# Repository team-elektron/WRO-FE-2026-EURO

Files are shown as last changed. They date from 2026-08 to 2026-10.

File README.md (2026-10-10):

# Elektron Team - WRO Future Engineers 2026 - European Open

## Introduction

We are Team Elektron from the High School of Electrical Engineering in Sarajevo, Bosnia & Herzegovina.
This is the public repo for our team and the work we have done on our robot for the Open Championship in Zagreb.

### Sponsors

This year we have the privilege of working together with our sponsors.

<table>
  <tr>
    <td width="25%" valign="center">
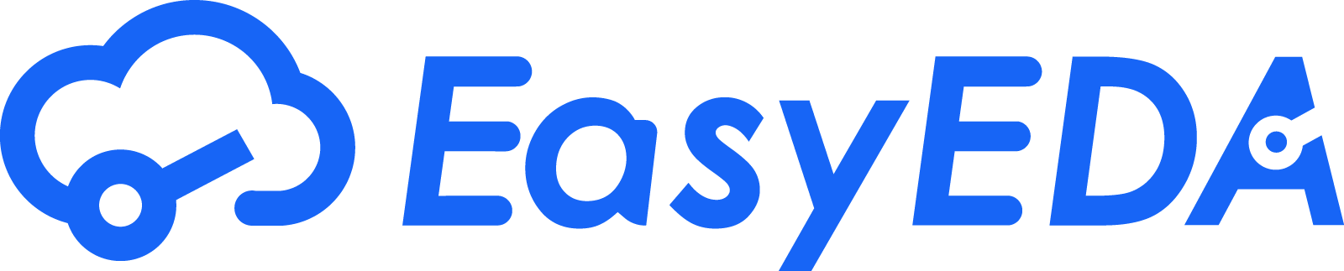
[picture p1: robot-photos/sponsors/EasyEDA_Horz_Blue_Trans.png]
EasyEDA
      
    </td>
    <td width="25%" valign="center">
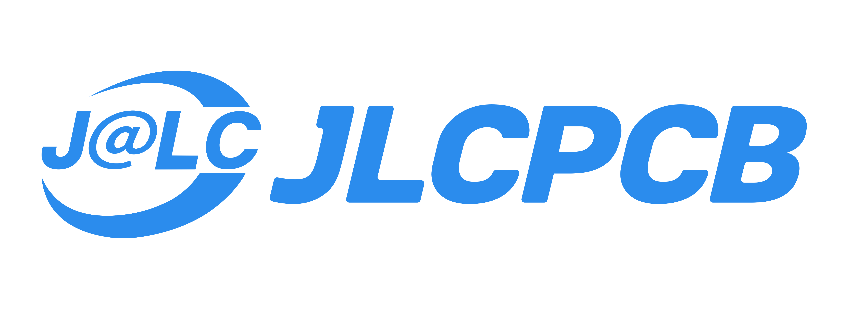
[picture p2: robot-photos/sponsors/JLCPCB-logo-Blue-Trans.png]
JLCPCB
      
    </td>
    <td width="25%" valign="center">
      <center><summary><h1>Birisal D.O.O.</h1></summary></center>
    </td>
  </tr>
</table>

### Robot Gallery

<table>
  <tr>
    <td width="25%" valign="center">
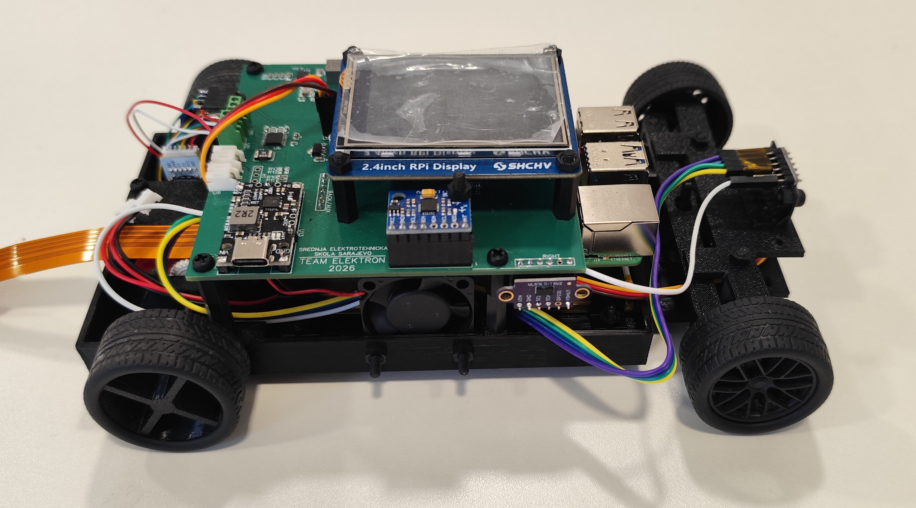
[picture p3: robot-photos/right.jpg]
      
    </td>
    <td width="25%" valign="center">
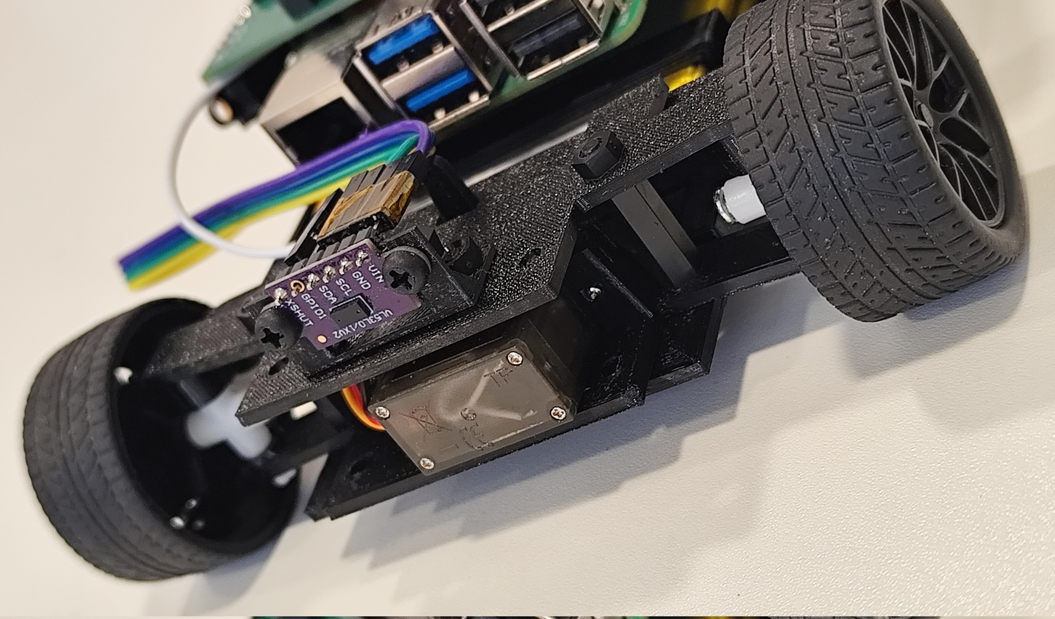
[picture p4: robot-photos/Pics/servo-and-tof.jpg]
      
    </td>
  </tr>
</table>

### Team Photo

<table>
  <tr>
    <td width="25%" valign="center">
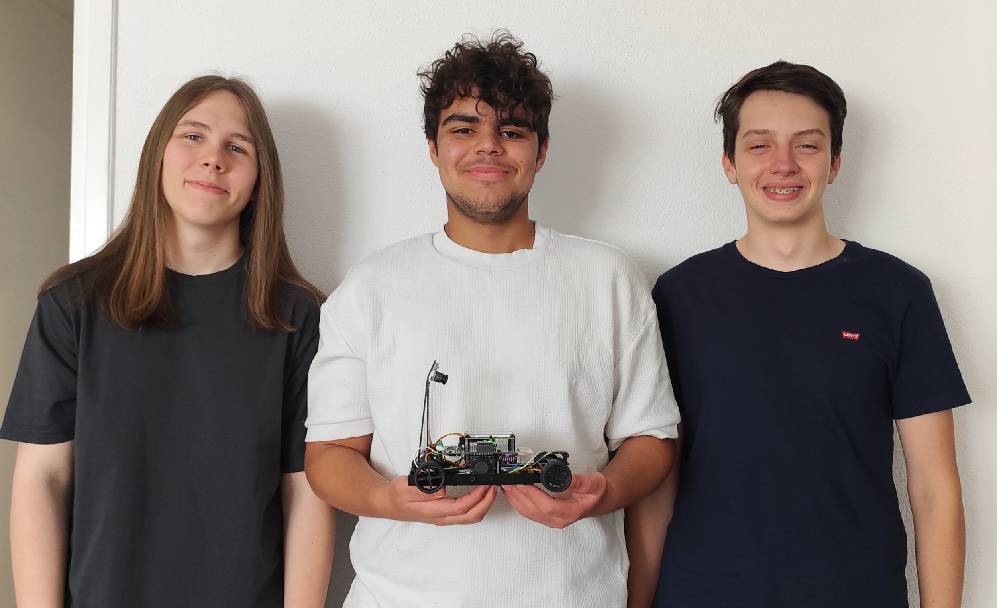
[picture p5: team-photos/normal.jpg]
      
    </td>
  </tr>
</table>

## Folder Content
* `team-photos` contains 2 photos of the team (an official one and one funny photo with all team members)
* `robot-photos` contains 6 photos of the vehicle (from every side, from top and bottom)
* `videos` contains the video.md file with the link to a video where driving demonstration exists
* `schematics` contains schematic diagrams of the driving base.
* `code` contains code of control software for all components which were programmed to participate in the competition.
* `3d-models` is for the files for models used by 3D printers to produce the vehicle elements.

## Navigation

- <a href="#introduction">Introduction</a>
- <a href="#sponsors">Sponsors</a>
- <a href="#team-photo">Team Photo</a>
- <a href="#robot-gallery">Robot Gallery</a>
- <a href="#changes-summary-from-the-national-competition">Changes summary from National Competition/a>
- <a href="#technical--mechanical-specifications">Technical & Mechanical Specifications</a>
  - <a href="#mechanics--drive">Mechanics & Drive</a>
  - <a href="#electronics">Electronics</a>
  - <a href="#size">Size</a>
- <a href="#how-does-it-work">How does it work?</a>
  - <a href="#driving-system">Driving System</a>
  - <a href="#steering-system">Steering System</a>
  - <a href="#power-and-power-delivery">Power & Power delivery system</a>
  - <a href="#the-brain">The brain (SBC, MCU)</a>
  - <a href="#sensors">Sensors</a>
- <a href="#bill-of-materials">Bill of Materials</a>
- <a href="#the-assembly-process-and-future-improvements">The assembly process and future improvements</a>
  - <a href="#pcb-assembly">PCB Assembly</a>
  - <a href="#3d-print--assembly">3d Print & Assembly</a>
- <a href="#code-explanation">Code Explanation</a>
  - <a href="#raspberry-pi-pico-2---pi-5-communications-bridge">Raspberry Pi Pico 2 <-> Pi 5 Communications bridge</a>
  - <a href="#open-challenge">Open Challenge</a>
  - <a href="#obstacle-challenge">Obstacle Challenge</a>

## Changes summary from the National competition
Our robot base has had major improvements done to it after the National championship in Zenica, Bosnia & Hercegovina.

Some of the biggest changes include:
- New motor/shaft gear ratio
- New robot control PCB
- New chassis design

## Technical & Mechanical Specifications

### Mechanics & Drive
- Fully custom built and 3d printed robot base
- High torque, high speed driving system
- Servo steering system

### Electronics
- 5Ah 2S battery pack (Li-Po)
- Time-of-Flight distance sensors
- Raspberry Pi 5 8GB SBC
- Raspberry Pi Pico 2 Zero MCU
- Full-axis IMU sensor
- Addressable LED indicators
- 2.4in TFT Touch Control LCD
- Raspberry Pi Camera Module 2 160 degree FOV

### Size
- 205x135x65mm (LxWxH) without camera mount, 205x135x~150mm (LxWxH) with camera mount
- ~490g total weight

<table>
  <tr>
    <td width="25%" valign="center">
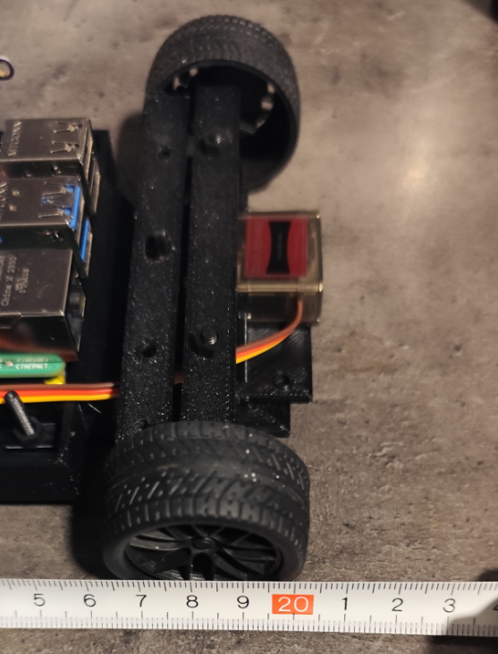
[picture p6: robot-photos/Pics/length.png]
      
    </td>
    <td width="25%" valign="center">
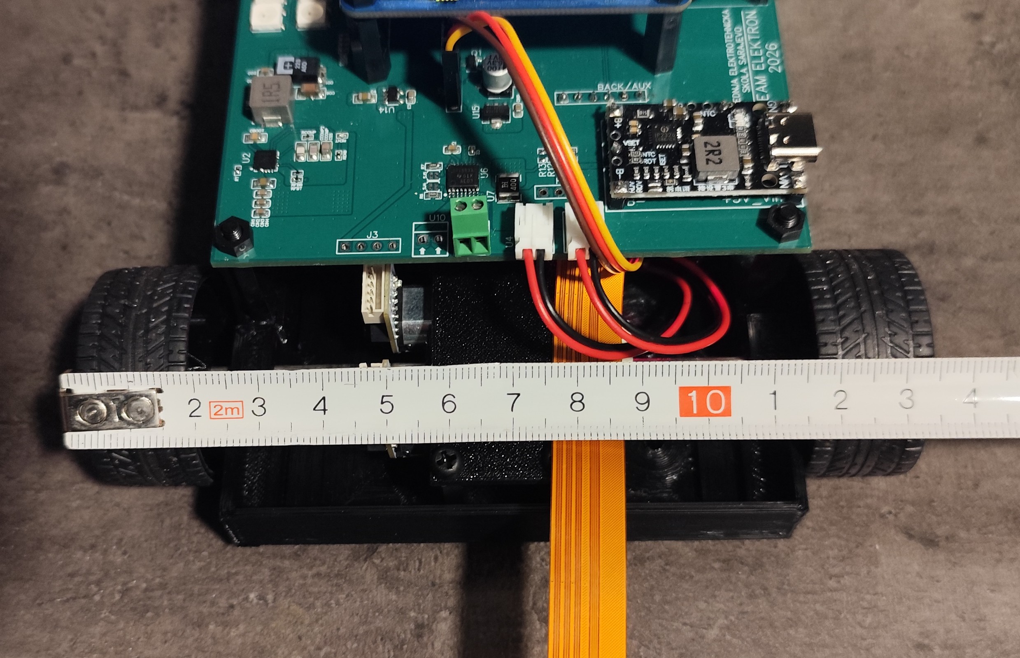
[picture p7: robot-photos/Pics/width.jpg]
      
    </td>
    <td width="25%" valign="center">
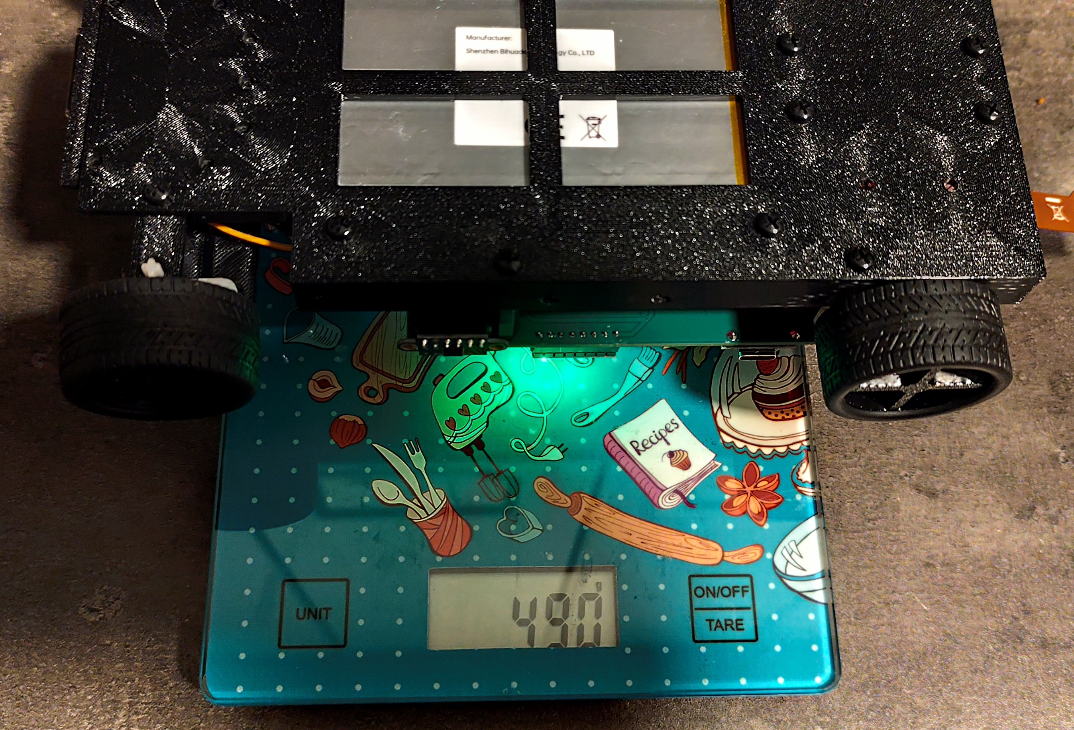
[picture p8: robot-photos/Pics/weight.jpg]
      
    </td>
  </tr>
</table>

## How does it work?

### Driving system
The main driving motors are 2 N30 motors in a 1:150 configuration, then the power is transferred to the wheels with a 1.67:1 gear ratio, the motors feature hall effect sensors. 

<table>
  <tr>
    <td width="25%" valign="center">
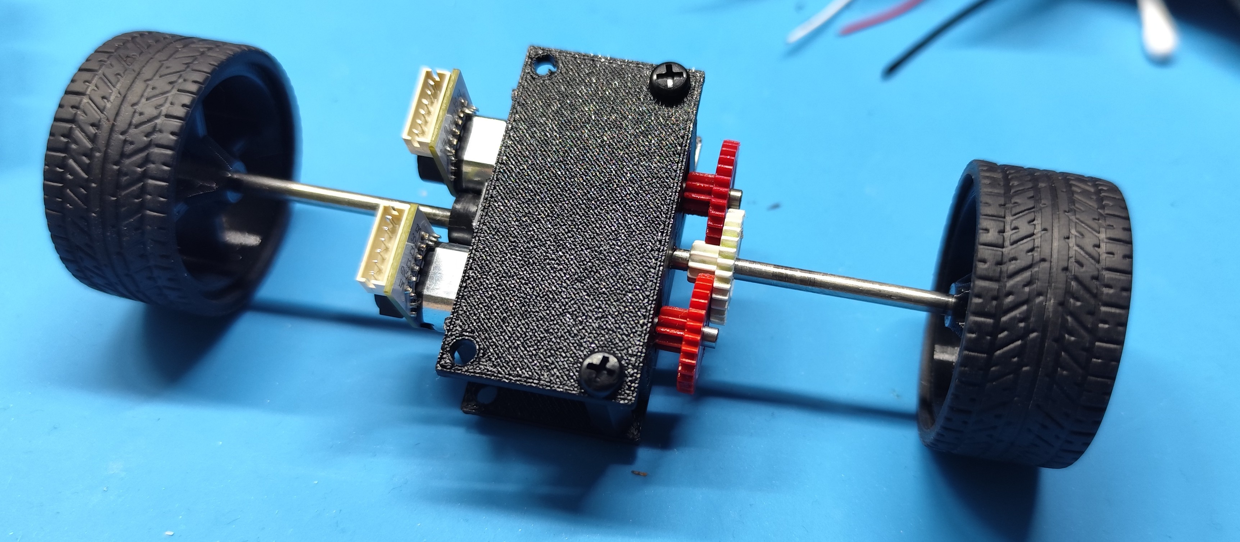
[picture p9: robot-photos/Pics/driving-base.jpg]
      
    </td>
    <td width="25%" valign="center">
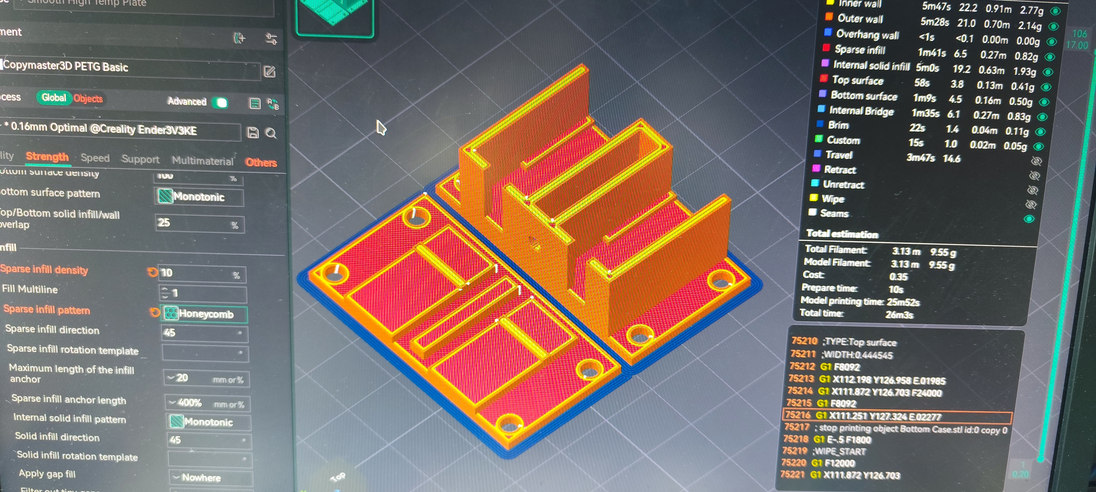
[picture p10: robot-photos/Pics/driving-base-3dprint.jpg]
      
    </td>
  </tr>
</table>

We have tested a couple different configurations (mainly 1:3, 1:1 and 1.67:1) out of which, 1.67:1 turned out to work the best for our needs. For extra torque, we decided to include 2 motors instead of one. They are connected to the DRV8833 H-Bridge IC on separate channels **BUT** the motors are connected onto one shared shaft together. The separte channels are exclusively to distribute load evenly on the IC.

<table>
  <tr>
    <th>Gear ratio (motor-shaft)</th>
    <th>Result</th>
    <th>Reasoning</th>
  </tr>
  <tr>
    <td>3:1</td>
    <td>Good speed, low torque/td>
    <td>With this combination we had very good speed, however our low end torque was very low which means parking the robot in Obstacle Challenge mode was almost impossible.</td>
  </tr>
  <tr>
    <td>1:1</td>
    <td>Slow, very torquey</td>
    <td>This gear ratio combination has really good low speed torque but it is painfully slow at full motor speed.</td>
  </tr>
  <tr>
    <td>1.67:1</td>
    <td>Decent speed, good torque</td>
    <td>This ratio has decent speed and good torque. It is OK for obstacle challenge parking.</td>
  </tr>
</table>

We are using a 110mm long and 3mm in diameter steel shaft and plastic gears.

Wheels are 3D printed, each wheel being 30mm in diameter without the outer rubber bits.

<table>
  <tr>
    <td width="25%" valign="center">
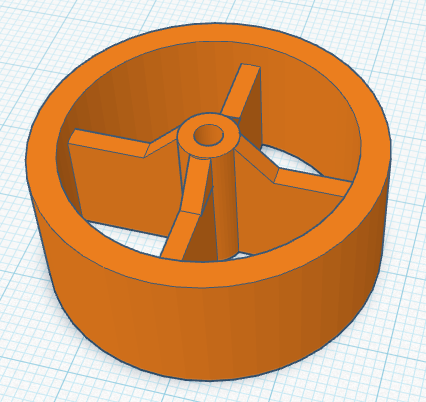
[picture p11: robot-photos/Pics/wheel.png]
      
    </td>
  </tr>
</table>

These specific motors have 2 hall effect sensors each, one for speed and one for direction, however we are only using one set from one motor, the other one stays disconnected and should only be used in case that something goes wrong with the other motor.

Speed control is done via a PID algorithm handled by the Pi Pico 2.

The motors are controlled by a DRV8833 IC which is current-limited to 1A per channel.

<table>
  <tr>
    <td width="25%" valign="center">
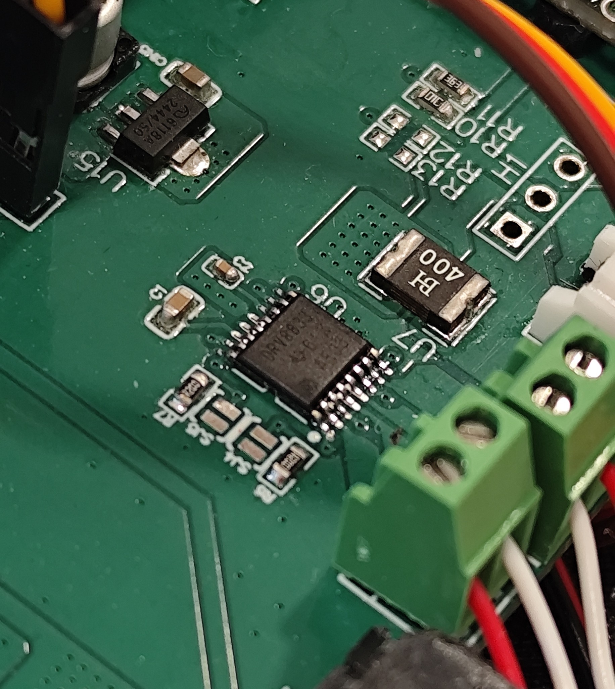
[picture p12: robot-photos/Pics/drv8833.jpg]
      
    </td>
    <td width="25%" valign="center">
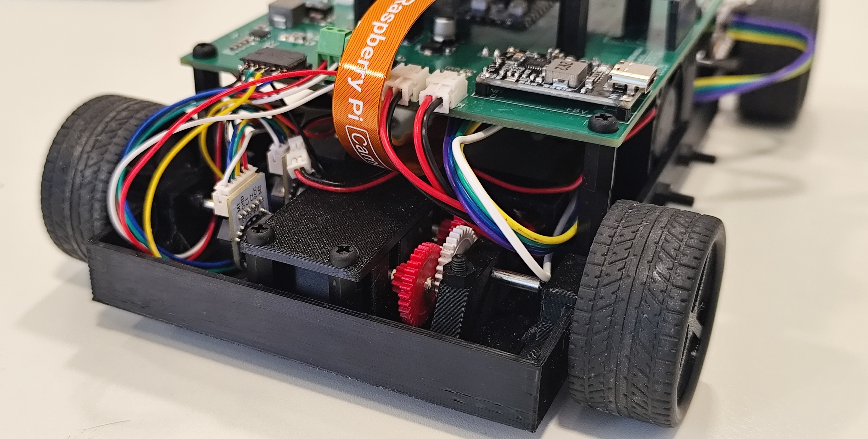
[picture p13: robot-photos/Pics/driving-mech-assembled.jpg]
      
    </td>
  </tr>
</table>

### Steering system
The steering system is controlled by one main MG90S servo from Waveshare.

Last year, we had issues with our steering system on the Open Championship in Ljubljana which was caused by a fake "metal" servo. Hence why we opted for higher quality full metal gear servos, and the MG90S was a great option as we didn't really need more power than that.

Steering power is transferred to the wheels via a steering shaft. Front wheels have bearings in them to remove drift caused by play in the old mechanism it is also used to decrease rolling resistance.
With this configuration, we are able to achieve a steering angle of 50 degrees to each side which fits our needs nicely.

<table>
  <tr>
    <td width="25%" valign="center">
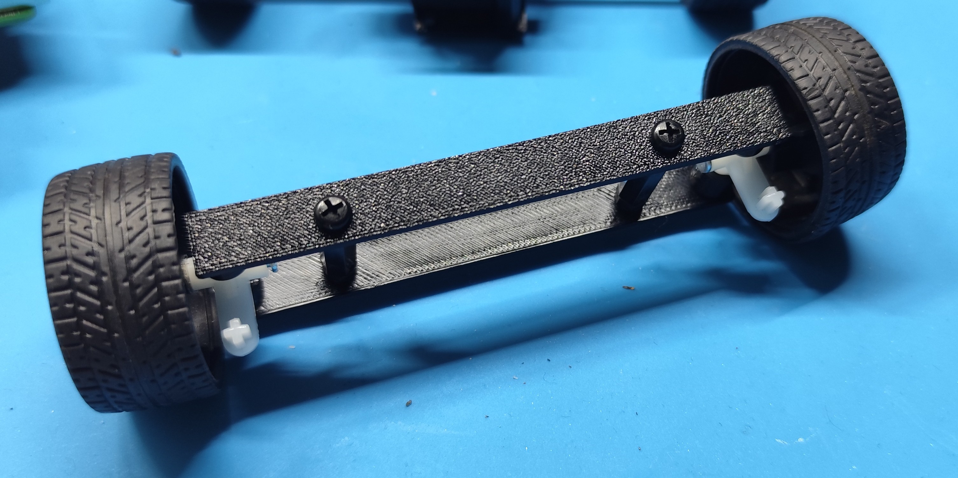
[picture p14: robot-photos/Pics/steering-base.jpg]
      
    </td>
    <td width="25%" valign="center">
      
    </td>
  </tr>
</table>

### Power and power delivery
We had originally thought about using a 3S battery system like we did last year, however, we switched to a 2S system now to save on space and weight. With some clever engineering tricks and overcomplication the power delivery side, that was super easy to do.

<p float="left">
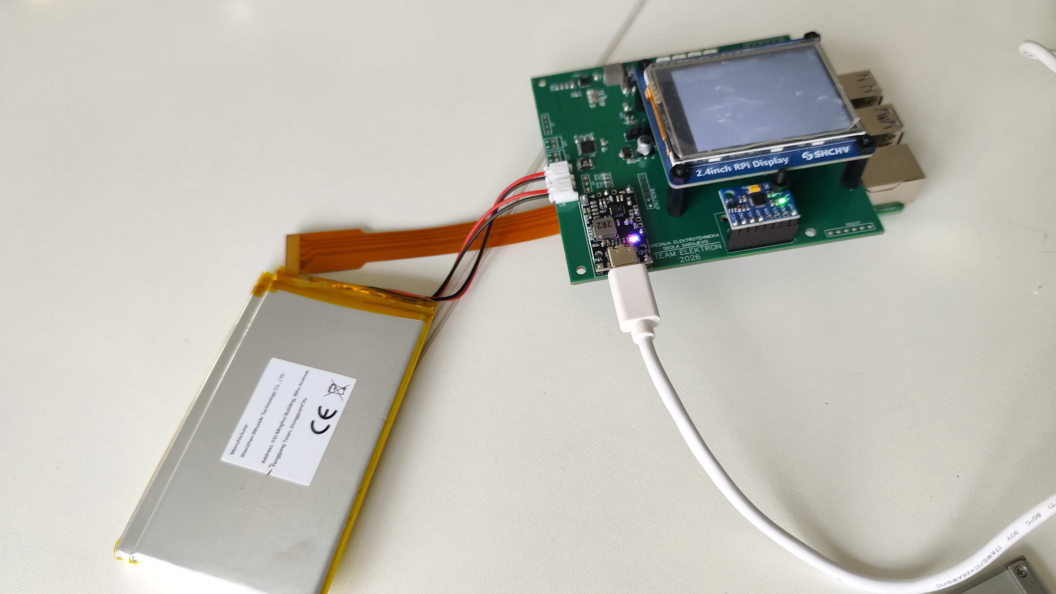
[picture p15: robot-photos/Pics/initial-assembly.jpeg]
  
  &nbsp;
</p>

The main power source are 2 5360105 Li-Po 3.7v 5Ah cells connected in series, they each have their own integrated BMS for safety.
We have decided to continue to charge our cells with a USB-C charger, but this year we have switched to a much more efficient IP2326 module for charging (and also because our previous battery had a dedicated BMS as it was built from bare 18650 cells and had balancing included which the 2 separate battery cells don't).

The actual power delivery part is split up into a couple different stages, one buck regulator for the Pi 5 exclusively and 2 smaller LDO regulators for the Pi Pico 2, sensors and another for the MG90S servo.

The main power regulator IC is a TPS54623RHLR. It's a pretty recent chip with not so much documentation available from other hobbyists but due to its very attractive price and great performance claims, we had to give it a shot. After designing a circuit that works for our needs in Ti's WEBENCH design utility (which are basically 5V output and at least 5A output max), we had ourselves a very nice and reliable regulator config. 

Robots are noisy machines, both literally in an audible sense, and power wise. Last year we had major issues with premade modules for power regulations which just couldn't handle our Pi, so this year, we decided to go overkill on ensuring our robot has clean power everywhere at all times. Our decoupling circuit includes:
  -  One 220uF 10V 10TPE220ML Panasonic Polymer Tantalum capacitor for bulk power storage.
  -  Two 10uF 6.3V X6S CL10X106MQ8NNNC Ceramic MLCC Samsung capacitors for mid frequency decoupling
  -  Four 100nF 6.3V X7R CGA0402X7R104K6R3GT Ceramic MLCC HRE capacitors for high frequency decoupling which were placed right next to the GPIO power pins of the Pi 5

<p float="left">
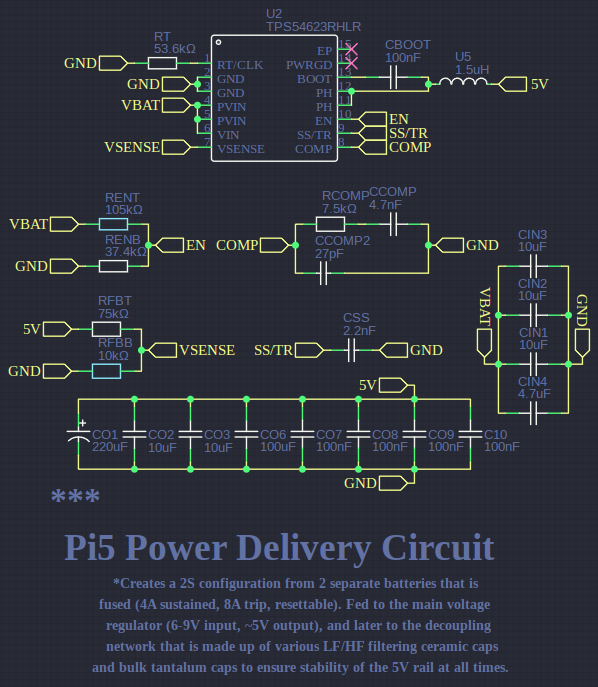
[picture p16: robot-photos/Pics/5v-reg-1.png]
  
  &nbsp;
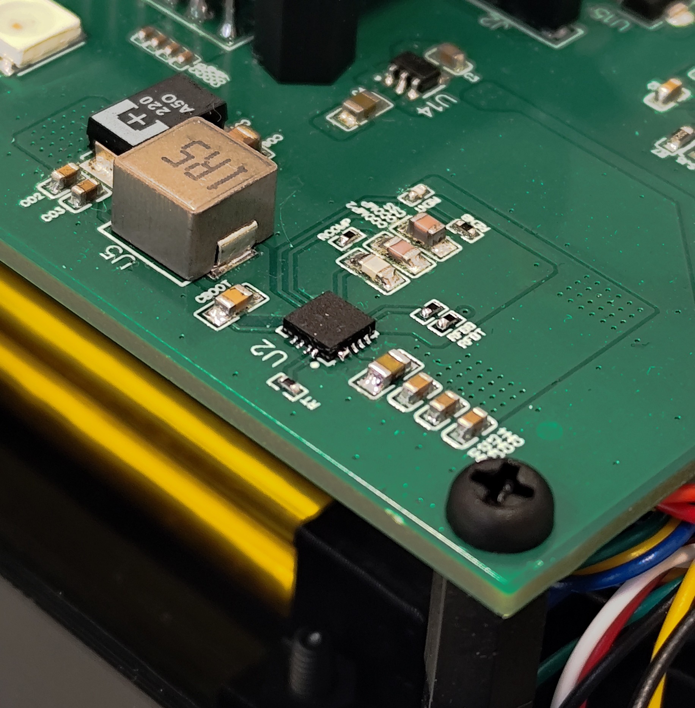
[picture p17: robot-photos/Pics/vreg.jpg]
  
</p>

For the other two power regulators, we decided to go with the following combination:
  - AP2112K-3.3TRG1 3.3V 1A LDO regulator for the Pico 2 and 3.3V sensors (ToF and IMU)
  - ME6118A50PG 5V 1A LDO regulator for our MG90S servo

<p float="left">
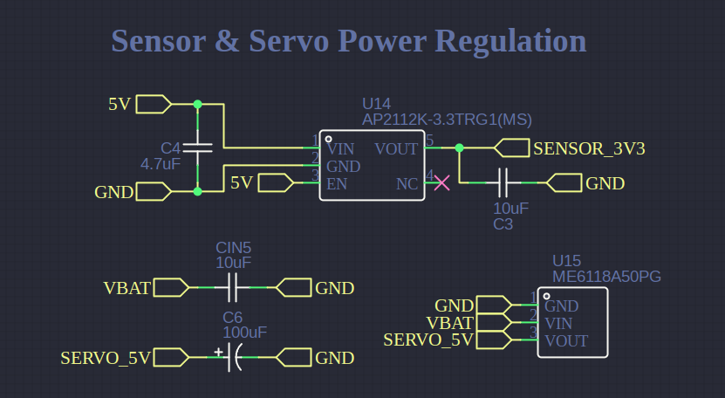
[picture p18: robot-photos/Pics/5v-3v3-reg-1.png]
  
  &nbsp;
</p>

### The Brain
Our robot runs on a Raspberry Pi 5 (8GB). We chose this SBC because we had it available and because the only other option we had was a Pi 4 with 2GB of ram. The choice is obvious :D
The Pi 5 communicates with the Pi Pico 2 Zero through UART on pins GP14/15 (and pins GP0/1 on the Pico 2). 

Workloads are distributed between both the SBC and the MCU like this:
<p float="left">
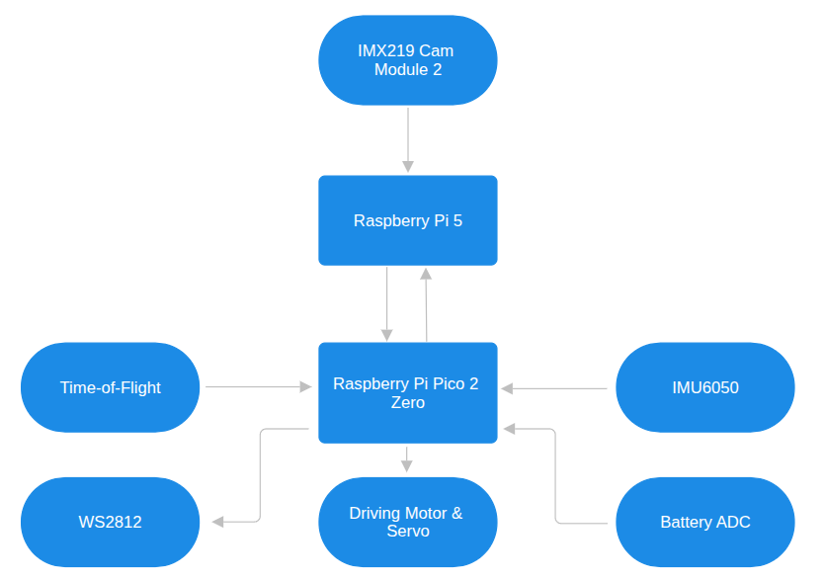
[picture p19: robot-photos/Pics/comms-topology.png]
  
  &nbsp;
</p>

Pi 5 Handles camera input and OpenCV image processing and then sends movement data to the Pi Pico 2 Zero. 

We use a simple UART protocol to communicate between the SBC and MCU:
- Every packet
  
  `[0xAA] [TYPE] [LEN] [PAYLOAD...] [CRC8]`
  - `0xAA` Start byte, always
  - `TYPE` What kind of message
  - `LEN` Payload length in bytes
  - `CRC8` Checksum of everything except start byte

- Pi 5 -> Pico 2 Zero (commands): `TYPE = 0x01`
  
  `[0xAA] [0x01] [04] [dir] [speed] [servo] [led_mode] [CRC8]`
  - `dir` 0 = stop, 1 = fwd, 2 = bwd
  - `speed` 0 - 255
  - `servo` 0 - 180
  - `led_mode` 0 = idle, 1 = driving, 2 = obstacle, 3 = low battery

- Pico 2 Zero -> Pi 5 (telemetry): `TYPE = 0x02`
  
  `[0xAA] [0x02] [14] [tof0_H] [tof0_L] [tof1_H] [tof1_L] [tof2_H] [tof2_L] [tof3_H] [tof3_L] [batt_H] [batt_L] [yaw_H] [yaw_L] [enc_H] [enc_L] [CRC8]`
  - ToF values in mm, split into HI/LO bytes
  - Battery in mV
  - Yaw in tenths of a degree (so 1234 = 123.4 degrees)
  - Encoder ticks as int16

The robot is controlled through the 2.4in TFT Touchscren LCD display. It also shows all of the telemetry data collected from the Pi Pico 2 Zero and allows for manual control when debugging. The competition-ready interface will just feature a simple option to select between running the obstacle or open challenge code and one start button. 

### Sensors
After running into a lot of trouble with ultrasonic distance sensors (hc-sr04) last year, we now use Time-of-Flight distance sensors. The most readily available sensor of this kind on the market is the VL53Lx series of sensors.

We use 3 ToF sensors on the robot with the option of adding a 4th sensor (rear side sensor) if needed. The data is polled in single shot mode on each sensor for higher speed and precision.

<p float="left">
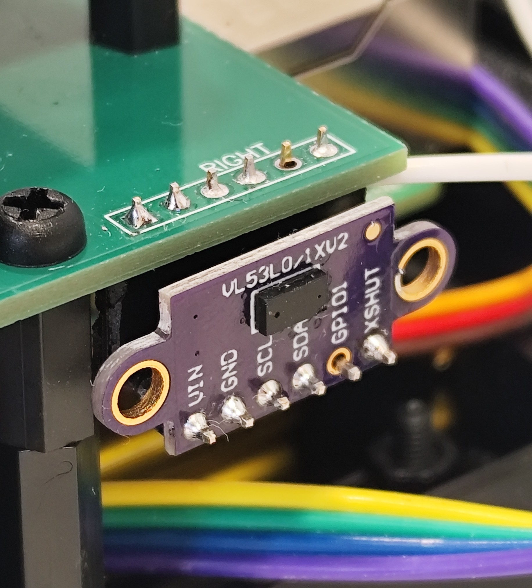
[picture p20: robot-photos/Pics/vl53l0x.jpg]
  
  &nbsp;
</p>

For getting the turn angle we use the MPU6050 IMU sensor. It's not the most accurate sensor and has a little bit of drift when idle but that's nothing resetting the sensor yaw angle before every turn cant fix. 

<p float="left">
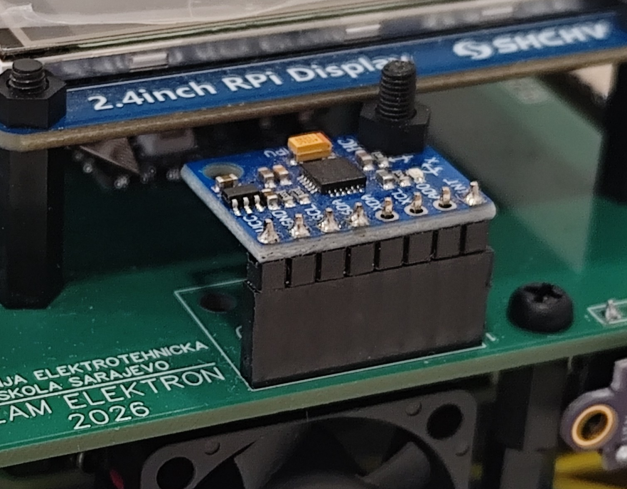
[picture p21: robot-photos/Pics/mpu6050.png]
  
  &nbsp;
</p>

## Bill Of Materials
- <a href="https://www.waveshare.com/rp2350-zero.htm">Raspberry Pi Pico 2 Zero (WaveShare)</a>
- <a href="https://sync.ba/product/raspberry-pi-5/">Raspberry Pi 5 8GB</a>
- <a href="https://share.temu.com/9bHhRICRygB">Time-of-Flight VL53L0x (Temu)</a>
- <a href="https://share.temu.com/IlQc3Dd6nUB">IMU6050 (Temu)</a>
- <a href="https://www.waveshare.com/mg90s-servo.htm">MG90S Metal 9g Servo (WaveShare)</a>
- <a href="https://www.aliexpress.com/item/1005009751662765.html">N30 1:150 w Hall sensor motor (AliExpress)</a>
- <a href="https://share.temu.com/7EXXP9jFbPB">5360105 3.7V 5000MAh Li-Po Battery (Temu)</a>
- <a href="https://share.temu.com/1M8ztQmiIdB">IP2326 2S Charger module (Temu)</a>
- <a href="https://github.com/team-elektron/WRO-FE-2026/blob/main/Schematics/BOM_WRO-FE-2026.csv">PCB Components BOM (LCSC)</a>

## The assembly process and future improvements

### PCB assembly

<p float="left">
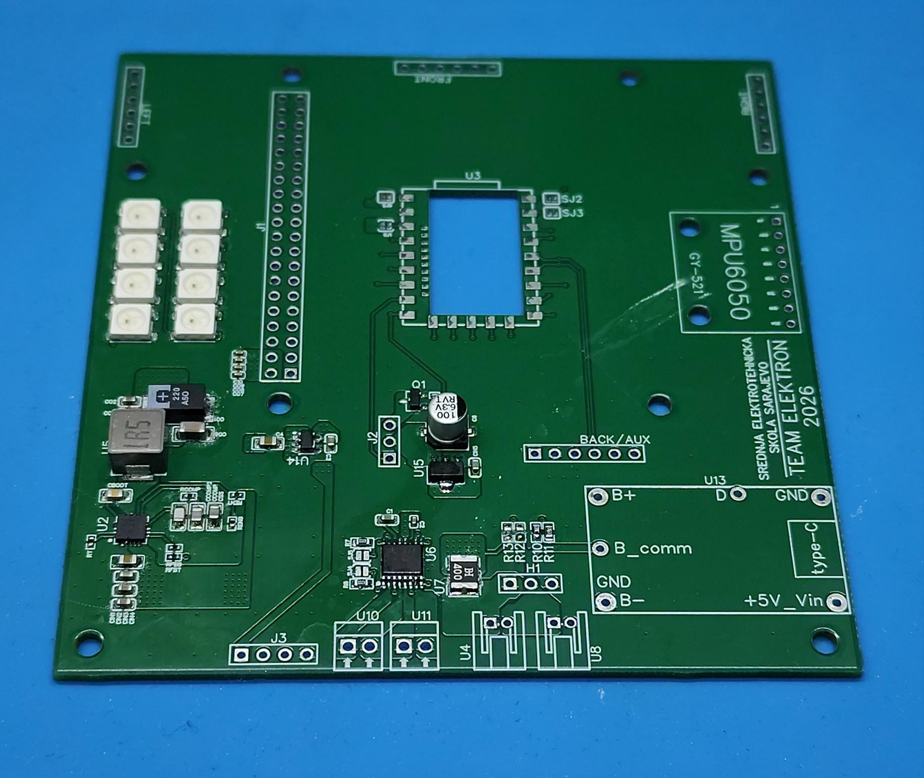
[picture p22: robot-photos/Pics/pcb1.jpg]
  
  &nbsp;
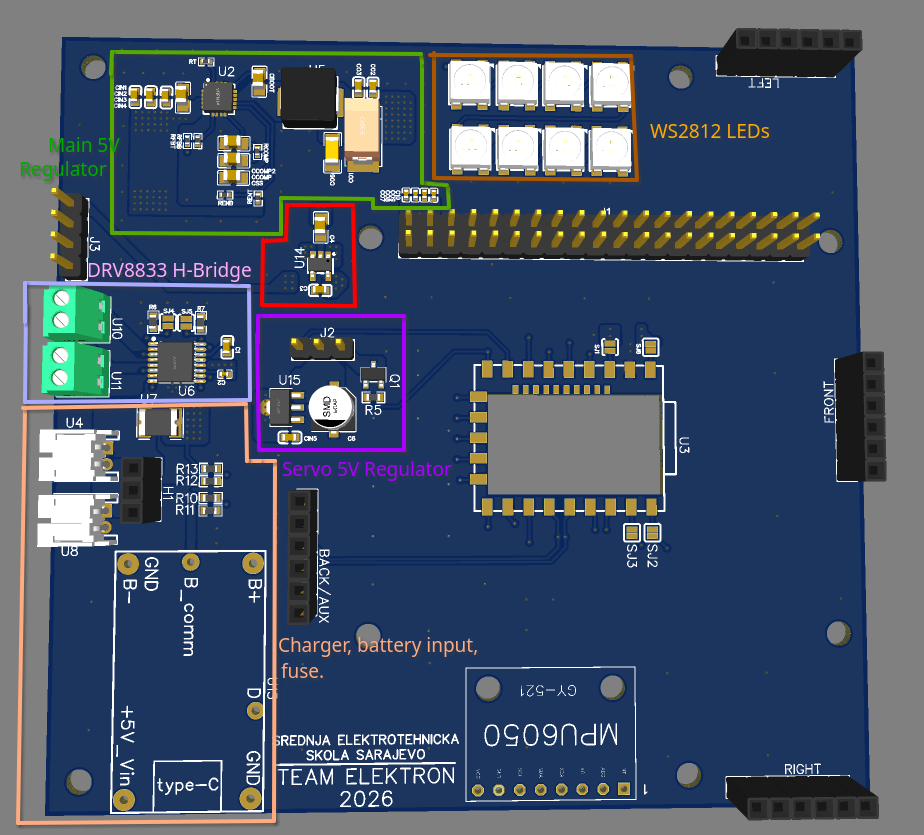
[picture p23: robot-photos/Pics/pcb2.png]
  
  &nbsp;
</p>

<a href="https://cloud.sphereconsoles.com/index.php/s/2eqJmXQ9cgKXqKD">Video of the assembly process</a>

We have designed a 4 layer PCB with a thickness of 1.6mm. The bottom layer carries the major power rails to their components along with providing a good ground plane. Middle layers carry all of the I2C, UART and other signal traces, and the top layer also acts like a ground plane for the most part. It has major power traces too and some but very few signal traces. The two copper GND planes are connected between the top and bottom layer by many vias throughout the whole PCB.

It is fully assembled by hand with our custom BGA station. All components were placed by hand. We used a solder paste with the Sn64Pb37 leaded formulation because of it's low melting point (~183c) and because it is easier to work with than lead-free solder paste. The trickiest part was soldering in the main 5V power regulator because of its VQFN-14 package, once it flowed into place, we had to rework it with a soldering iron to get rid of the aditional paste that oozed out to the sides + a nudge test with added AMTECH 559-V2-TF flux to ensure all of the solder joints flowed correctly. The PCB worked on the first try. 

### 3d Print & Assembly
Most of the robot parts are plastic and 3D printed. We used an Ender 3 V3 KE to print all of our parts. All of the 3D designs are available in the 3D Designs folder.
The robot is held together by M3 Nylon screws and standoffs. We used these instead of brass screws/standoffs because of the weight advantage they provide. 

<p float="left">
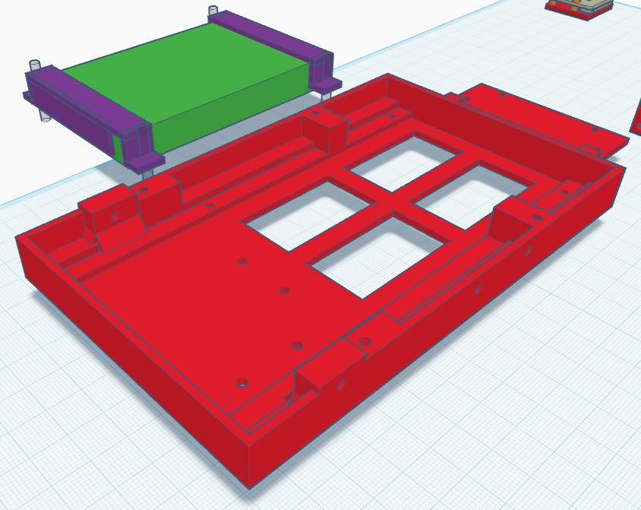
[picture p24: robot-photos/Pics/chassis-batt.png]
  
  &nbsp;
</p>

The main chassis was printed with Copymaster3D PETG filament like all other components with the most notable settings being the use of 3 wall loops for extra strength. This is also the heaviest 3D printed part of our robot and the most important one structurally. Previous printing tests with 2 wall loops have shown that the model is prone to flexing under load which is not ideal so after adding another "rail" in our design and printing it with 3 wall loops, 4 bottom shell layers, 4 top shell layers and 50% honeycomb infill, we got a very nice and solid robot chassis.

<p float="left">
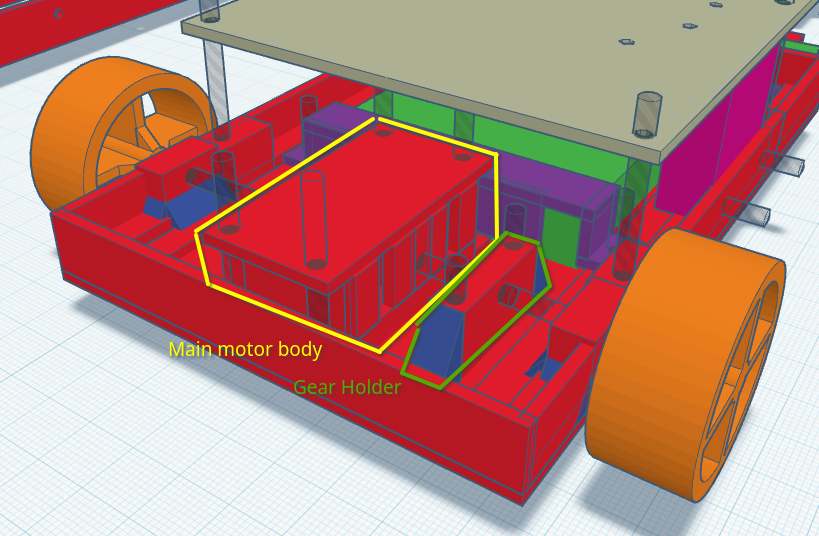
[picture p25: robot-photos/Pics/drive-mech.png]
  
  &nbsp;
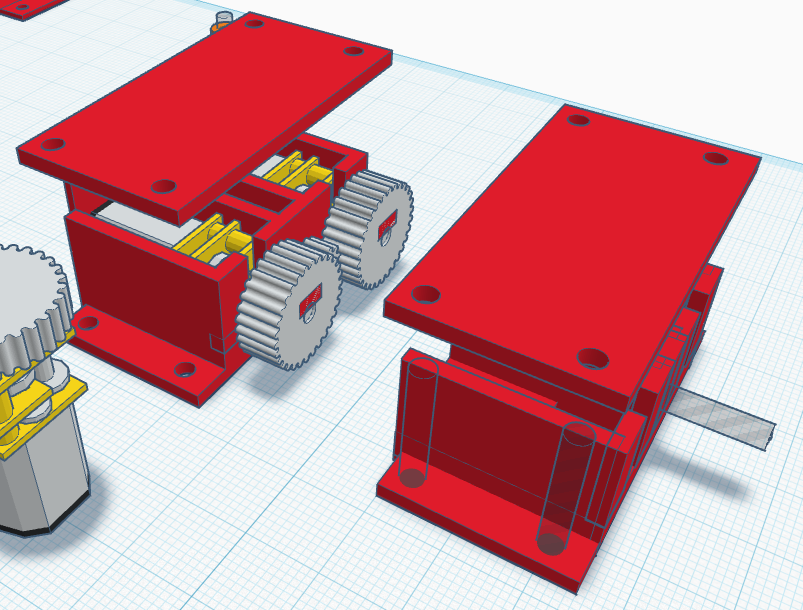
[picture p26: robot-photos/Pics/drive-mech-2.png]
  
</p>

The main driving body holds in the 2 N30 motors. It's made from 2 separate pieces which screw down together, this same driving base has the camera tower mount screwed down onto it. It's printed with the same filament as the chassis and 3 wall loops and 30% honeycomb infill.
Right next to the main driving case is the gear holder as can be seen in the photos above. It makes sure all gears remain in one spot and don't move anywhere.
We have decided to keep the main wheel mounts integrated into the chassis but after having to take apart the robot case to dissasemble the driving mechanism multiple times, we have decided that it's best to make these detachable next time. 

<p float="left">
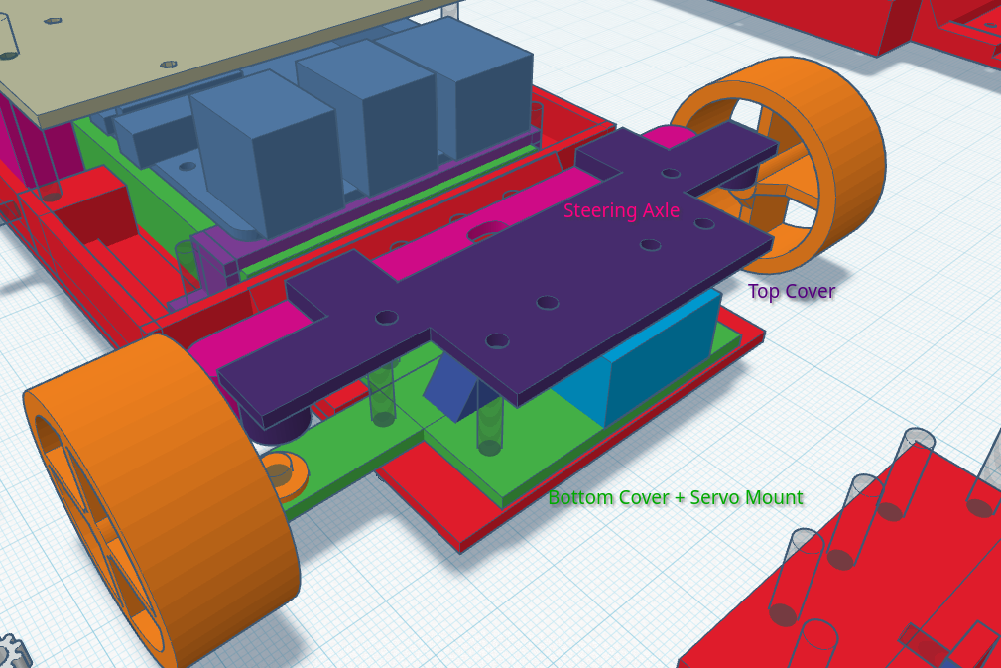
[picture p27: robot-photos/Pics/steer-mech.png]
  
  &nbsp;
</p>

The steering mechanism is built from 3 different pieces:
  1. Bottom (Base) + Servo holder
  2. Steering Axle
  3. Top Cover + ToF Sensor Holder

They are connected together with Nylon screws (bottom and top part, the steering axle is connected to the servo). All 3 parts are printed with PETG filament with 3 wall loops, 30% honeycomb infill.
This design has had many changes until we settled on the most reliable design although it's center is not very precise. That's another thing we will improve next time. For now, we are compensating for the losses via software.

## Code Explanation

### Raspberry Pi Pico 2 <-> Pi 5 Communications bridge
Our robot is split into 2 control units, the Pi Pico 2 which handles the sensors and motors and communicates with the Pi 5. The Pi 5 handles the code for the open and obstacle challenge.
These 2 components communicate via UART.

<p float="left">
  
  &nbsp;
</p>

### Open Challenge

Our open code works by scanning for the color coded lines on the track using its camera. After a line is detected the robot uses its IMU sensor to turn exactly 90 degrees once the turn is completed it uses its ToF sensors to center to the walls. It counts laps and corners after all 3 laps are completed it continues to its starting position where it finishes its run. This year we are using LAB color space to decrease false detections.

### Obstacle challenge

<table>
  <tr>
    <td width="25%" valign="center">
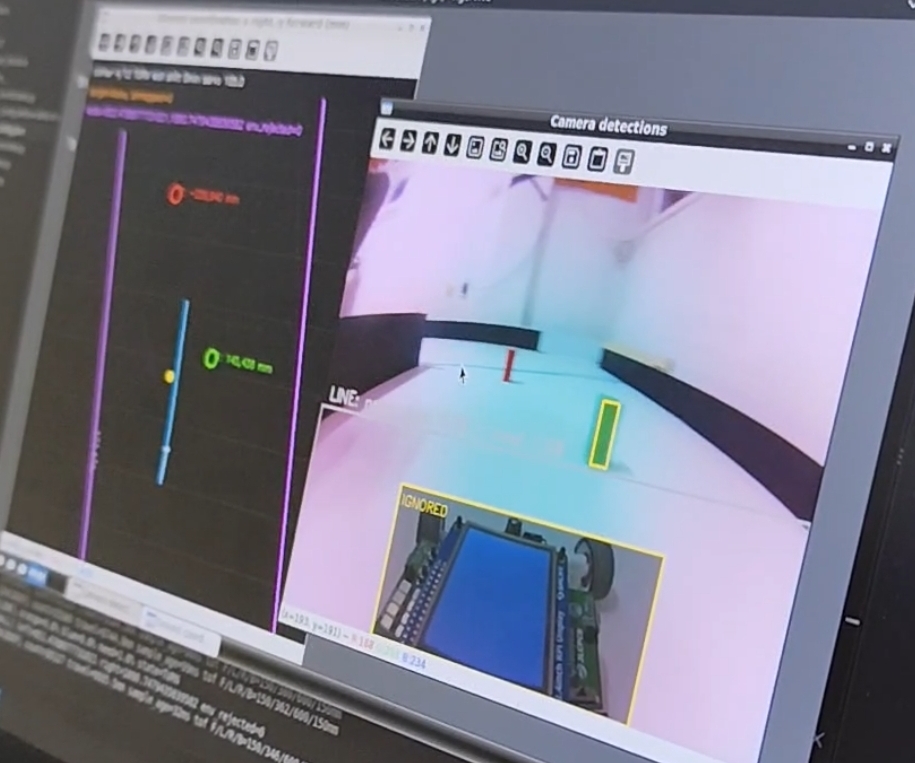
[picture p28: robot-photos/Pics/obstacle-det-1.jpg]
      
    </td>
    <td width="25%" valign="center">
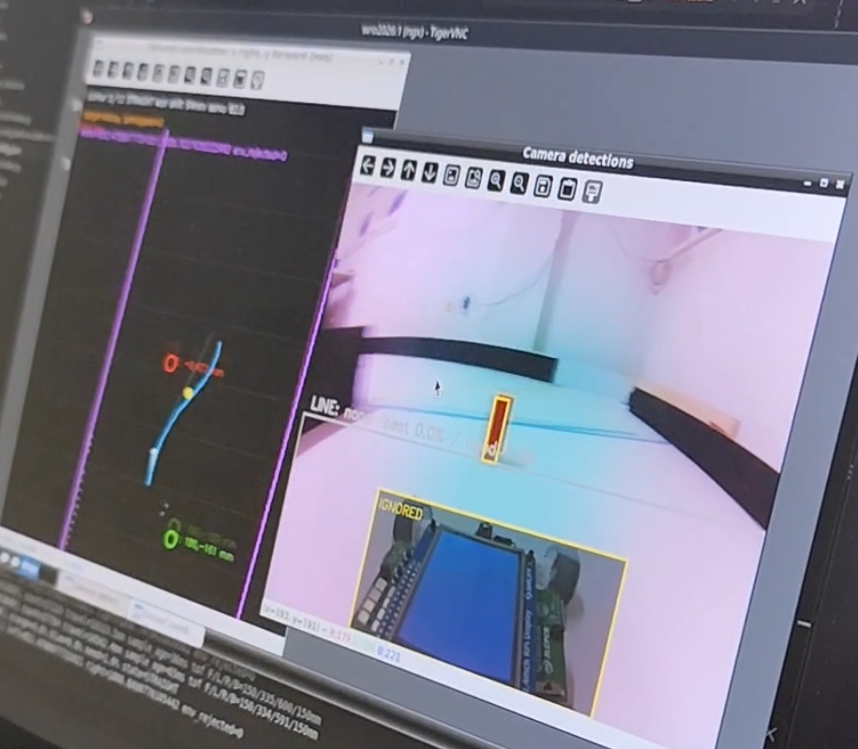
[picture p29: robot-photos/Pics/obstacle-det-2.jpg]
      
    </td>
  </tr>
</table>

On the first lap the robot maps out the walls and obstacles using the camera and ToF sensors to make the other laps easier. When an obstacle is detected the robot runs 4 seperate simulations to confirm if it can pass the obstacle safely or must reverse and re adjust. If a obstacle appears right after or right before a turn the robot will use its front and back ToF sensors to confirm that it is safe to reverse and adjust to pass the obstacle on the correct side and safely complete the turn. The mapping we use also makes parking easier as when the robot starts in the parking area it simultaneously maps out the parking box so parking itself is a much simpler task.

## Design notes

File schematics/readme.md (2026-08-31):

# Schematic Diagrams & Gerbers

You can find the schematic diagram and PCB gerber files for our robot here.

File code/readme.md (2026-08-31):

# Code

In this folder you can find all of the code used on the robot.

##Folder contents:
- `pico2pi5-bridge` Contains the code for the UART bridge between the Pi Pico 2 Zero and the Pi 5 SBC
- `open-challenge-cv` Contains the code for the Open Challenge with OpenCV (Camera support)
- `open-challenge-nocv` Contains the code for the Open Challenge without OpenCV (analog, using raw ToF & IMU logic, fallback in case the camera module fails)
- `obstacle-challenge` Contains the Obstacle Challenge code

### Digital robot structure:
Pi 5 SBC:
- OS: <a href="https://downloads.raspberrypi.com/raspios_arm64/images/raspios_arm64-2026-06-19/2026-06-18-raspios-trixie-arm64.img.xz">Debian 13 Trixie arm64 64bit</a>
- TFT LCD: 2.4" with <a href="https://github.com/goodtft/LCD-show">LCD-Show2.4</a> via GPIO pins
- PC Connectivity: RealVNC & OpenSSH Server via LAN/WiFi with custom dual monitor for VNC/LCD separation 

Pi Pico 2 Zero MCU:
- Bootloader: <a href="https://github.com/earlephilhower/arduino-pico">Arduino for PICO</a>
- Connectivity to Pi 5 SBC: UART
- Connectivity to sensors: I2C via multiplexer

### Bridge Interface:
The bridge interface consists of a Python3 graphical and CLI script which is displayed on the Pi 5's LCD display and/or runs in the background. It translates OpenCV data from instructions like `steer: 100` to code that the Pi Pico 2 understands and the same thing in reverse. The full UART comms protocol can be found in the main README of the project.

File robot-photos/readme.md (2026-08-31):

# Robot Photos

Here you can find all of the pictures of our robot and the pictures of the assembly process.
- This folder contains 6 basic pictures of the robot from all sides
- The `Pics` folder contains the pictures from the designing/assembling and debugging process

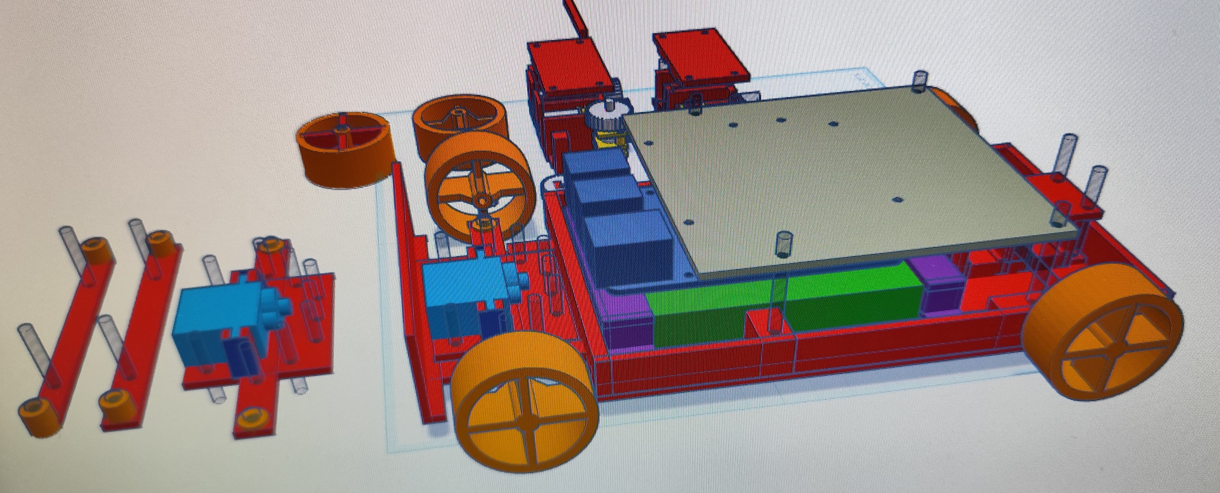
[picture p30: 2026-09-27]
robot-photos/Pics/3d-design-full.jpg

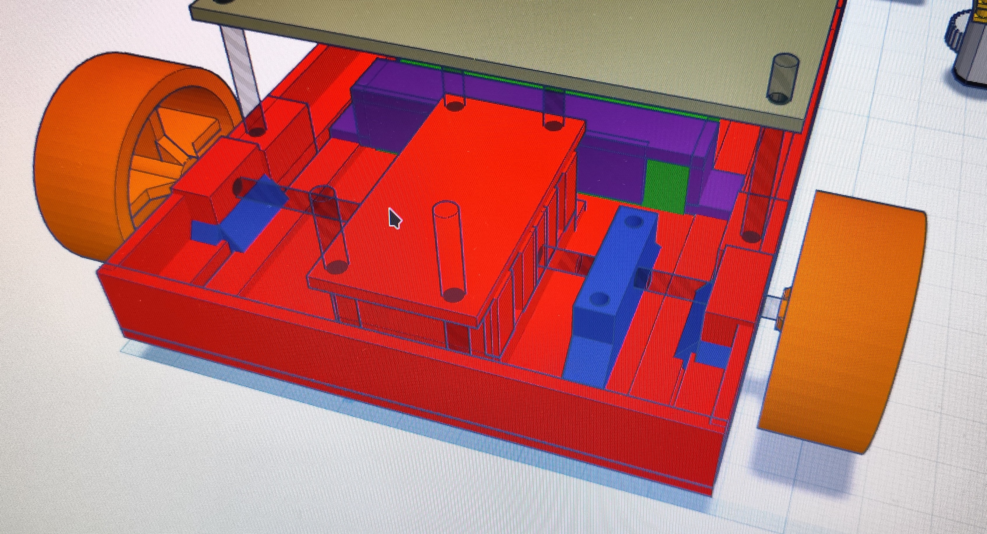
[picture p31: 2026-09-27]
robot-photos/Pics/3d-design-rear.jpg

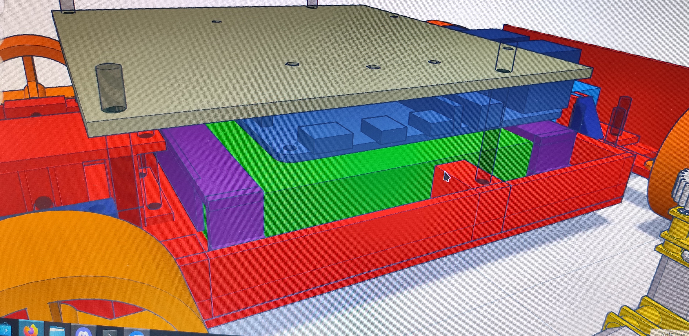
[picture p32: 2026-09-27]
robot-photos/Pics/3d-design-right.jpg

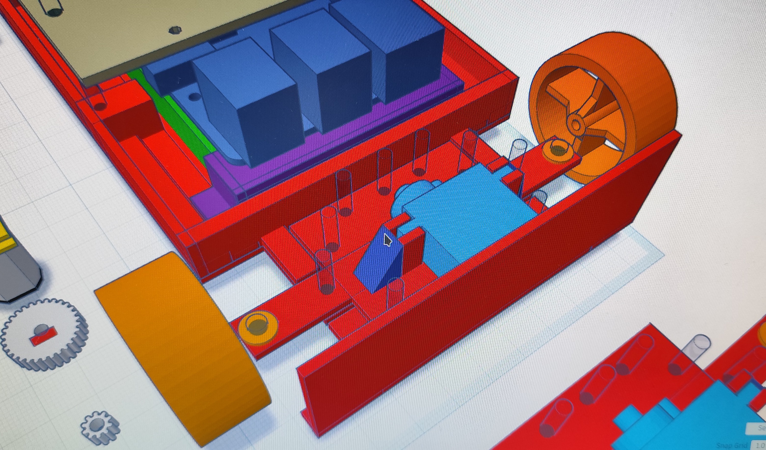
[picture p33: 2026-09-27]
robot-photos/Pics/3d-design-front.jpg

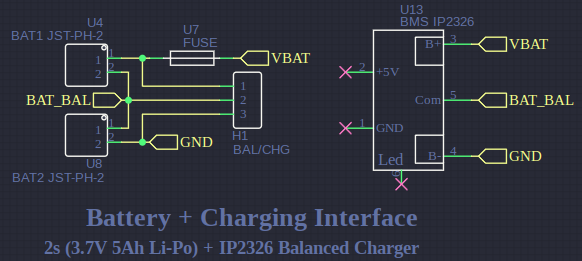
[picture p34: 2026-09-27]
robot-photos/Pics/bat-chg-prot.png

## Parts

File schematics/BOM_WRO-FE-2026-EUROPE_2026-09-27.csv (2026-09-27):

ID | Name | Designator | Footprint | Quantity | Manufacturer Part | Manufacturer | Supplier | Supplier Part | Price
1 | MPU6050_4P | MPU6050 | MPU6050_4P | 1
2 | NC | SJ2,SJ3 | SJ_2S | 2
3 | SERVO | J2 | HDR-M-2.54_1X3 | 1 |  |  | LCSC | C180248
4 | MS-12D08G3.5 | POWER_SW | SW-TH_MS-12D08G3.5 | 1 | MS-12D08G3.5 | HOOYA(皓宇电子) | LCSC | C2939255
5 | OBSTACLE_START | OBSTACLE_START | KEY-TH_4P-L6.0-W6.0-P4.50-LS6.5 | 1 | K2-1102DP-E4SW-04 | 韩国韩荣 | LCSC | C136684
6 | 10uF | C1,CIN5,CIN3,CIN2,CIN1 | C0603 | 5 | CL10A106MP8NNNC | SAMSUNG(三星) | LCSC | C85713
7 | 100nF | C2 | C0402 | 1 | CC0402KRX7R6BB104 | YAGEO(国巨) | LCSC | C309458
8 | 10uF | C5,C32,C33,C34,C35,CO3,CO2,C3 | C0603 | 8 | CL10X106MQ8NNNC | SAMSUNG(三星) | LCSC | C318634
9 | 100nF | C7,C8,C9,C18,C19,C30,C31,CO9,CO8,CO7,C10 | C0402 | 11 | CGA0402X7R104K6R3GT | HRE(芯声) | LCSC | C22435938
10 | 47nF | C11,C12 | R0402 | 2 | FCC0402B473K250AT | FOJAN(富捷) | LCSC | C5137574
11 | 4.7uF | C13 | C0402 | 1 | FCC0402X475M100AT | FOJAN(富捷) | LCSC | C46635918
12 | 330nF | C14 | C0603 | 1 | 0603F334M500NT | FH(风华) | LCSC | C14790
13 | 100nF | C15,C16,C17,C37,C38,C39 | C0603 | 6 | CC0603X7R50V104KN | TORCH(火炬) | LCSC | C53084449
14 | 10uF | C20,C21,C22,C23,C24,C25,C26,C27,C28,C29 | C0603 | 10 | CGA0603X5R106M250JT | HRE(芯声) | LCSC | C6119874
15 | 1nF | C36 | C0402 | 1 | TCC0402X7R102M500AT | CCTC(三环) | LCSC | C696907
16 | GP6 | J4 | HDR-M-2.54_1X1 | 1 |  |  | LCSC | C81276
17 | TP_BAL | BAL_TP | HDR-M-2.54_1X1 | 1 |  |  | LCSC | C81276
18 | GP7 | J6 | HDR-M-2.54_1X1 | 1 |  |  | LCSC | C81276
19 | GP8 | J7 | HDR-M-2.54_1X1 | 1 |  |  | LCSC | C81276
20 | K4-6×6_TH | OPEN_START | KEY-TH_4P-L6.0-W6.0-P4.50-LS6.5 | 1 | K2-1102DP-E4SW-04 | 韩国韩荣 | LCSC | C136684
21 | 1uH | L1 | IND-SMD_L7.1-W6.5-P5.60 | 1 | SPM6530T-1R0M120 | TDK | LCSC | C87572
22 | GL0603UY01 | CHG | LED-SMD_L1.6-W0.8-R-RD | 1 | GL0603UY01 | Guiguang light(桂光光电) | LCSC | C51933295
23 | TW4409B | Q2 | SOIC-8_L4.9-W3.9-P1.27-LS6.0-BL | 1 | TW4409B | TWGMC(迪嘉) | LCSC | C42417417
24 | CH221K | Q3 | SOT-23-6_L2.9-W1.6-P0.95-LS2.8-BL-2 | 1 | CH221K | WCH(南京沁恒) | LCSC | C5125736
25 | AO3400A | Q4 | SOT-23-3_L2.9-W1.3-P1.90-LS2.4-BR | 1 | AO3400A | AOS | LCSC | C20917
26 | AO3401A | Q5 | SOT-23_L2.9-W1.3-P1.90-LS2.4-BR | 1 | AO3401A | AOS | LCSC | C15127
27 | 10kΩ | R1,R2,R3,R4,R9,R18,R22,R10,R5 | R0603 | 9 | RC0603FR-0710KL | YAGEO(国巨) | LCSC | C98220
28 | 47kΩ | R8 | R0603 | 1 | FRC0603F4702TS | FOJAN(富捷) | LCSC | C2907042
29 | 100kΩ | R12 | R0603 | 1 | FRC0603F1003TS | FOJAN(富捷) | LCSC | C2906980
30 | 24kΩ | V_CFG | R0603 | 1 | 0603WAJ0243T5E | UNI-ROYAL(厚声) | LCSC | C25588
31 | 6.04kΩ | R14 | R0603 | 1 | NQ03WAF6041T5E | UNI-ROYAL(厚声) | LCSC | C50670195
32 | 100Ω | R15 | R0402 | 1 | CR0402F100RQ10Z | EVER OHMS(天二科技) | LCSC | C881021
33 | 20Ω | R16 | R2512 | 1 | FRP2512J200 TS | FOJAN(富捷) | LCSC | C7468114
34 | 100Ω | R17,R23,R24 | R0603 | 3 | FRR0603J101 TS | FOJAN(富捷) | LCSC | C49196788
35 | 5.23kΩ | R19 | R0402 | 1 | FRC0402F5231TS | FOJAN(富捷) | LCSC | C2933105
36 | 30.1kΩ | R20 | R0402 | 1 | FRC0402F3012TS | FOJAN(富捷) | LCSC | C2998131
37 | 2.2kΩ | R21 | R0402 | 1 | FRC0402F2201TS | FOJAN(富捷) | LCSC | C2906865
38 | 4.7kΩ | RN1,RN2,RN3,RN4,RN5,RN6,RN7,RN8,RN9 | RES-ARRAY-SMD_0603-4P-L1.6-W1.6-BL | 9 | 2D03WGJ0472T5E | UNI-ROYAL(厚声) | LCSC | C2769375
39 | SJ_NO | SJ1,SJ6,SJ7 | SJ_2S-NO | 3
40 | TCA9548APWR | U1 | TSSOP-24_L7.8-W4.4-P0.65-LS6.4-BL | 1 | TCA9548APWR | TI(德州仪器) | LCSC | C130026
41 | LSM6DSV16XTR | U9 | LGA-14_L3.0-W2.5-P0.50-BR | 1 | LSM6DSV16XTR | ST(意法半导体) | LCSC | C5267406
42 | BQ29209DRBR | U13 | SON-8_L3.0-W3.0-P0.65-LS3.0-BL-EP | 1 | BQ29209DRBR | TI(德州仪器) | LCSC | C139352
43 | BQ25792RQMR | U16 | QFN-29_L4.0-W4.0-P0.40-TL-BQ25792RQMR | 1 | BQ25792RQMR | TI(德州仪器) | LCSC | C2862876
44 | MT52B103F3950F01000 | BATTEMP | RES-TH_BD2.0-P1.80-D0.3 | 1 | MT52B103F3950F01000 | STE(松田) | LCSC | C3000141
45 | HYCW575-USBC06-680B | CHARGE | USB-C-SMD_HYCW575-USBC06-680B | 1 | HYCW575-USBC06-680B | HOAUC(华宇创) | LCSC | C42400234
46 | MOTOR_1_HALL | J3 | HDR-M-2.54_1X4 | 1 |  |  | LCSC | C124378
47 | WS2812E-V5 | LED6,LED7,LED8,LED9,LED5,LED4,LED3,LED2 | LED-SMD_4P-L5.0-W5.0-LS5.4-TL-1 | 8 | WS2812E-V5 | worldsemi | LCSC | C2920042
48 | BAT2 | BAT2 | CONN-TH_S2B-PH-K-S-LF-SN | 1 | S2B-PH-K-S(LF)(SN) | JST | LCSC | C173752
49 | BAT1 | BAT1 | CONN-TH_S2B-PH-K-S-LF-SN | 1 | S2B-PH-K-S(LF)(SN) | JST | LCSC | C173752
50 | 105kΩ | RENT | R0402 | 1 | 0402WGF1053TCE | UNI-ROYAL(厚声) | LCSC | C25742
51 | 10kΩ | RFBB | R0402 | 1 | RC0402FR-7W10KL | YAGEO(国巨) | LCSC | C851848
52 | RP2040-ZERO | U3 | COMM-SMD_RP2040-ZERO | 1 | RP2040-Zero | Waveshare(微雪电子) | LCSC | C5350143
53 | ME6118A50PG | U15 | SOT-89-3_L4.5-W2.5-P1.50-LS4.2-BR | 1 | ME6118A50PG | MICRONE(南京微盟) | LCSC | C2835802
54 | AP2112K-3.3TRG1(MS) | U14 | SOT-23-5_L2.9-W1.6-P0.95-LS2.7-BR | 1 | AP2112K-3.3TRG1(MS) | MSKSEMI(美森科) | LCSC | C22365427
55 | MOTOR2 | U11 | CONN-TH_DB125-2.54-2P-GN | 1 | DB125-2.54-2P-GN-S | DORABO(地博电气) | LCSC | C918120
56 | MOTOR1 | U10 | CONN-TH_DB125-2.54-2P-GN | 1 | DB125-2.54-2P-GN-S | DORABO(地博电气) | LCSC | C918120
57 | FUSE | U7 | F1812 | 1 | BSMD1812-400-12V | BHFUSE(佰宏) | LCSC | C18164540
58 | DRV8833PWP | U6 | TSSOP-16_L5.0-W4.4-P0.65-LS6.4-BL-EP | 1 | DRV8833PWPR | TI(德州仪器) | LCSC | C50506
59 | 1.5uH | U5 | IND-SMD_L7.2-W6.6_GPSR07X0 | 1 | CYA0650-1.5UH | SHOU HAN(首韩) | LCSC | C5189751
60 | TPS54623RHLR | U2 | VQFN-14_L3.5-W3.5-P0.50-TL-EP_TPS54622RHLT | 1 |  | TI(德州仪器) | LCSC | C560970
61 | NO | SJ5,SJ4 | SJ_2S-NO | 2
62 | 53.6kΩ | RT | R0402 | 1 | RC0402FR-0753K6L | YAGEO(国巨) | LCSC | C273330
63 | VL53L0x_3 | RIGHT | HDR-F-2.54_1X6 | 1 |  |  | LCSC | C40877
64 | 75kΩ | RFBT | R0402 | 1 | CRCW040275K0FKED | VISHAY(威世) | LCSC | C482234
65 | 37.4kΩ | RENB | R0402 | 1 | RC0402FR-0737K4L | YAGEO(国巨) | LCSC | C185422
66 | 7.5kΩ | RCOMP | R0402 | 1 | CRCW04027K50FKED | VISHAY(威世) | LCSC | C482236
67 | 36kΩ | R11 | R0603 | 1 | RC0603FR-0736KL | YAGEO(国巨) | LCSC | C114619
68 | 200mΩ | R7,R6 | R0603 | 2 | RTT03R20JTP | RALEC(旺诠) | LCSC | C158890
69 | IRLML6344 | Q1 | SOT-23-3_L3.0-W1.6-P1.90-LS2.8-BR | 1 | IRLML6344TR(UMW) | UMW(友台半导体) | LCSC | C5271195
70 | VL53L0x_2 | LEFT | HDR-F-2.54_1X6 | 1 |  |  | LCSC | C40877
71 | 40P_GPIO | J1 | HDR-M-2.54_2X20 | 1 |  |  | LCSC | C50980
72 | BAL/CHG | H1 | HDR-F-2.54_1X3 | 1 |  |  | LCSC | C146690
73 | VL53L0x_1 | FRONT | HDR-F-2.54_1X6 | 1 |  |  | LCSC | C40877
74 | 2.2nF | CSS | C0805 | 1 | CL21C222JBFNNNE | SAMSUNG(三星) | LCSC | C28260
75 | 100uF | CO6 | C1206 | 1 | TCC1206X5R107M6R3HT | CCTC(三环) | LCSC | C380356
76 | 220uF | CO1 | CAP-SMD_L7.3-W4.3 | 1 | 10TPE220ML | PANASONIC(松下) | LCSC | C147767
77 | 4.7uF | CIN4,C4 | C0805 | 2 | TMK212BBJ475MD-T | TAIYO YUDEN(太诱) | LCSC | C650989
78 | 27pF | CCOMP2 | C0805 | 1 | CC0805JRNPO9BN270 | YAGEO(国巨) | LCSC | C107113
79 | 4.7nF | CCOMP | C0805 | 1 | CGA4C2C0G1H472JT0Y0N | TDK | LCSC | C338091
80 | 100nF | CBOOT | C0805 | 1 | C0805C104K3RACTU | KEMET(基美) | LCSC | C1711
81 | 100uF | C6 | CAP-SMD_BD5.0-L5.3-W5.3-RD | 1 | RVT0J101M0505 | ROQANG(容强) | LCSC | C72472
82 | VL53L0x_4 | BACK/AUX | HDR-F-2.54_1X6 | 1 |  |  | LCSC | C40877

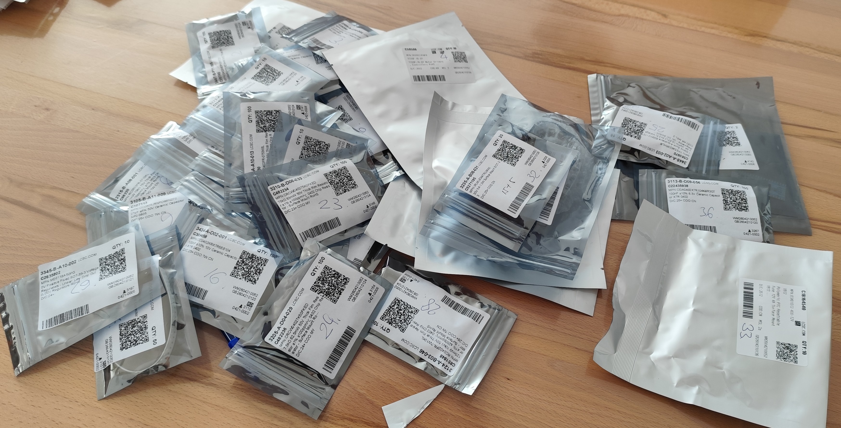
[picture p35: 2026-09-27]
robot-photos/Pics/parts-pile.jpg

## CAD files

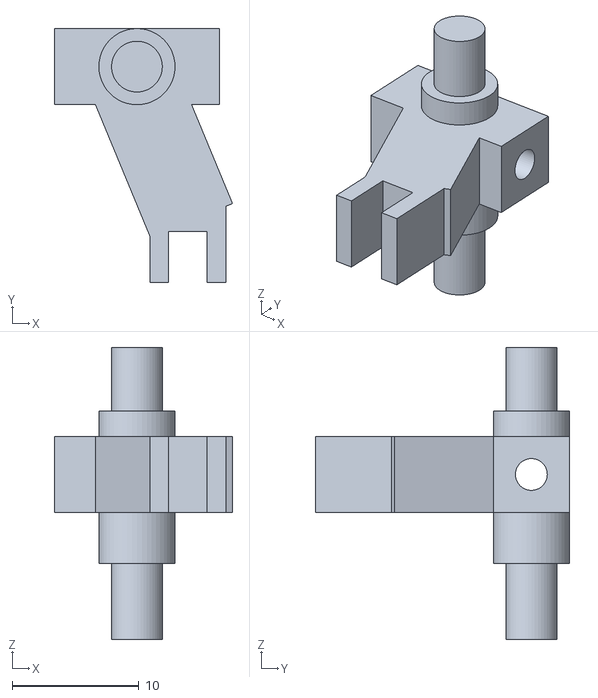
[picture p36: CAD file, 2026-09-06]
3d-models/steering/newsteering-arm-right.stl
14.0 x 20.0 x 23.0

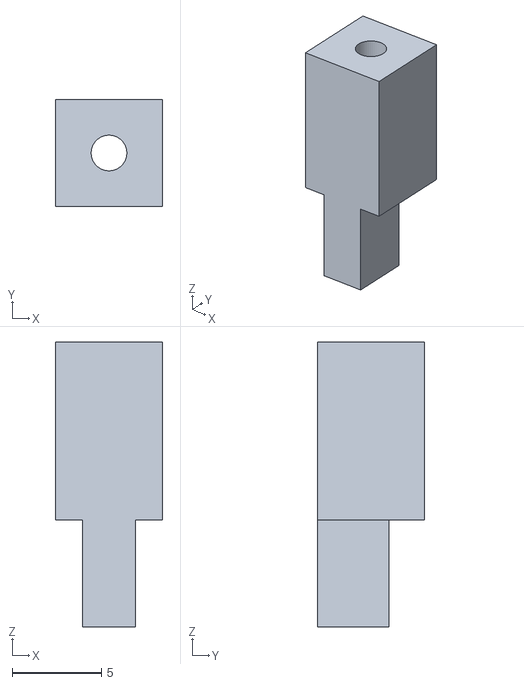
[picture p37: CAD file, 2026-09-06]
3d-models/steering/newsteering-arm-adapter.stl
6.00 x 6.00 x 16.0

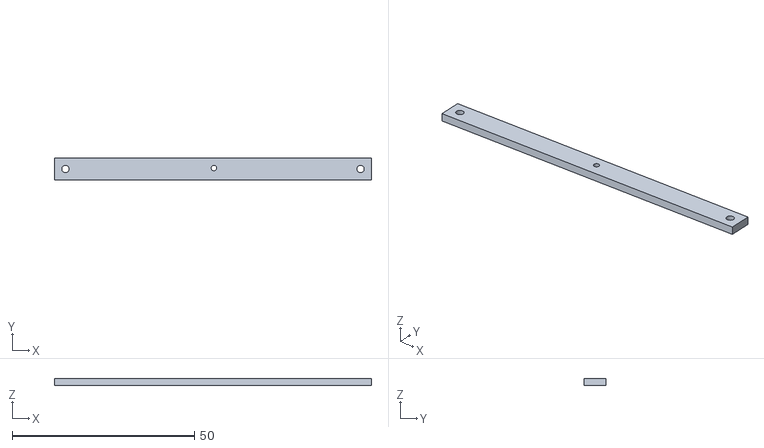
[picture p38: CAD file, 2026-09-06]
3d-models/steering/newsteering-arm-swing.stl
87.0 x 6.00 x 2.00

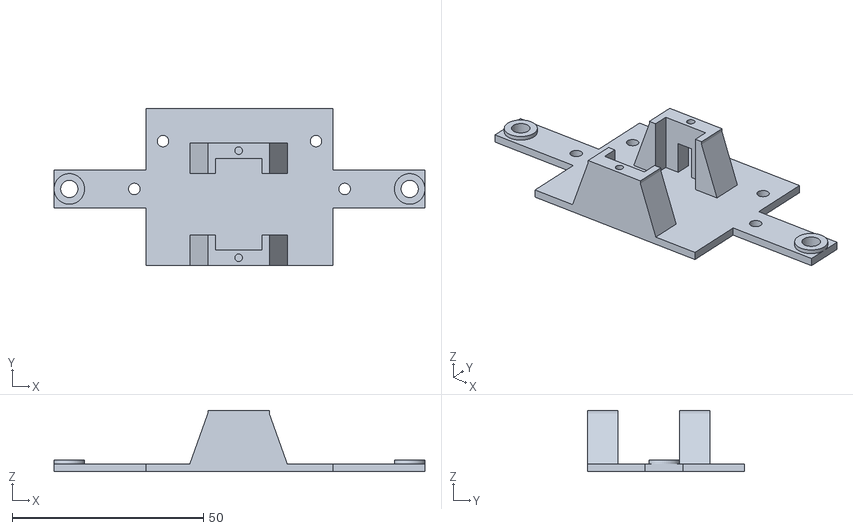
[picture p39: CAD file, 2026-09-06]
3d-models/steering/newsteering-bottom-bracket.stl
97.0 x 41.0 x 16.0

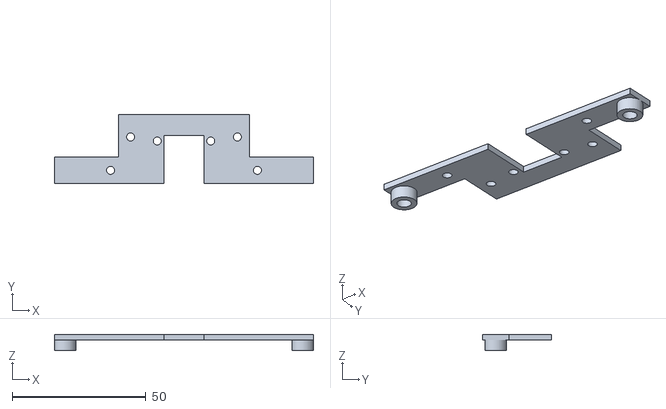
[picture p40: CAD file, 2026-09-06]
3d-models/steering/newsteering-top-bracket.stl
97.0 x 26.0 x 6.00

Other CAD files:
3d-models/steering/newsteering-arm-left.stl

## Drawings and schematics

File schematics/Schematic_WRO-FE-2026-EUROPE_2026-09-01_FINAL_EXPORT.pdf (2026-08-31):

## VL53L1 ToF

# H-BRIDGE Circuit

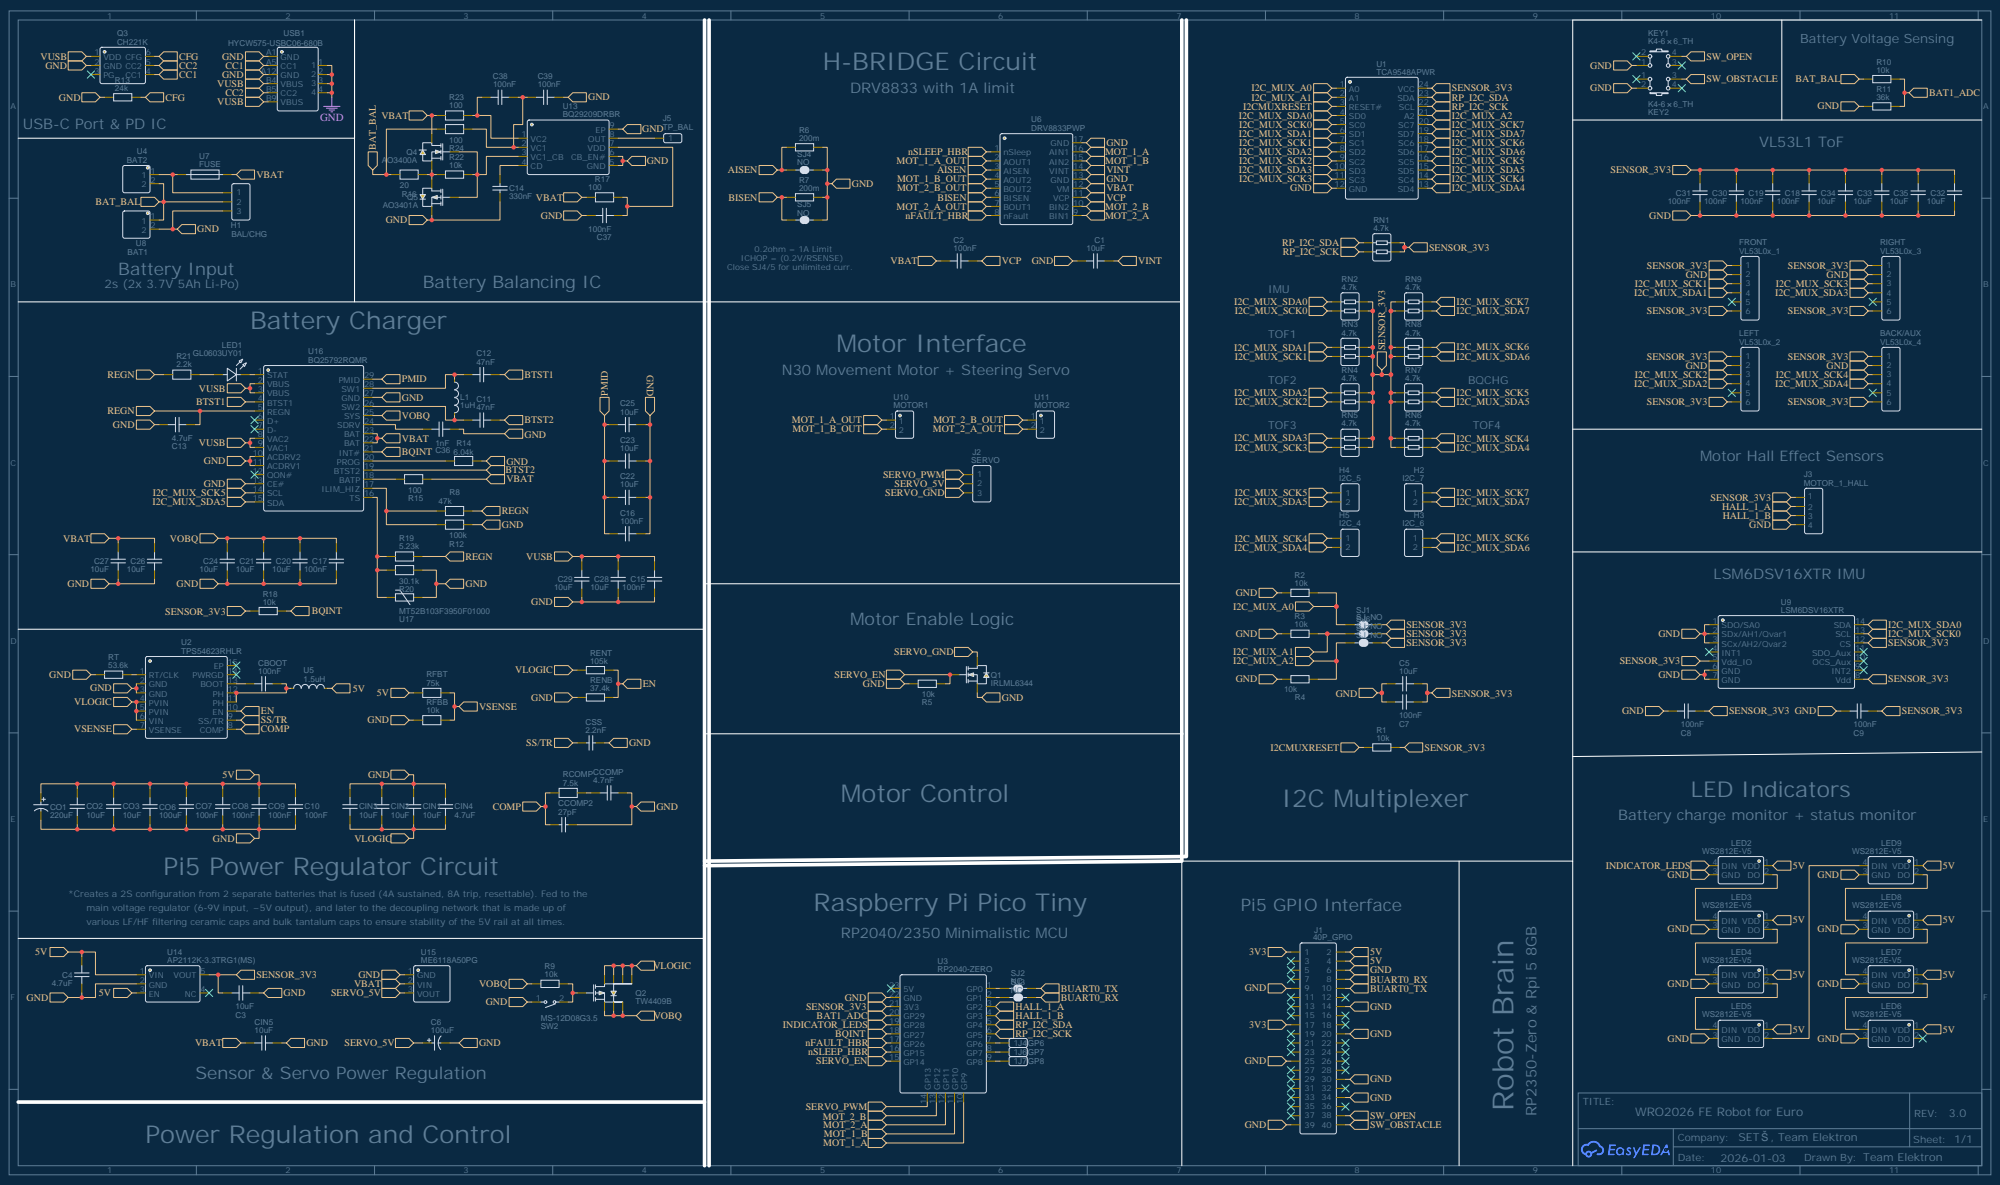
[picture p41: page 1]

USB-C Port & PD IC

0.2ohm = 1A Limit
ICHOP = (0.2V/RSENSE)
Close SJ4/5 for unlimited curr.

N30 Movement Motor + Steering Servo

Motor Hall Effect Sensors

TPS54623RHLR
EN 10 PH 11 PH 12 BOOT 13 PWRGD 14 EP 15

Battery charge monitor + status monitor

*Creates a 2S configuration from 2 separate batteries that is fused (4A sustained, 8A trip, resettable). Fed to the
main voltage regulator (6-9V input, ~5V output), and later to the decoupling network that is made up of
various LF/HF filtering ceramic caps and bulk tantalum caps to ensure stability of the 5V rail at all times.

Raspberry Pi Pico Tiny

Company: SET , Team Elektron

Drawn By: Team Elektron

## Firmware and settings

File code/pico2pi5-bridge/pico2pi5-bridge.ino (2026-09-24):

//
//  Team Elektron - WRO Future Engineers 2026
//  RP2350 (Pico 2) dual-core firmware
//
//  Core 0: motors, servo, encoder, IMU, PID
//  Core 1: ToF sensors, UART, battery ADC, LEDs
//

#include "pico/multicore.h"
#include "pico/mutex.h"
#include <Wire.h>

#include "pins.h"
#include "shared_state.h"
#include "motors.h"
#include "encoder.h"
#include "pid.h"
#include "sensors_imu.h"
#include "sensors_tof.h"
#include "battery.h"
#include "leds.h"
#include "uart_comms.h"

// Shared state definition

RobotState g_state = {};
    mutex_t    g_mutex;
    mutex_t    g_wire_mutex;   

// Core 0 timing
static uint32_t t_pid   = 0;   // 10ms  — PID update
static uint32_t t_imu   = 0;   // 20ms  — IMU read
static uint32_t t_servo = 0;   // 20ms  — servo slew step
static uint32_t t_telem = 0;   // 100ms — write telem to shared state

//  CORE 1 — sensors, UART, LEDs, battery

void core1_main() {
    tof_init();
    battery_init();
    uart_init();
    leds_init();
    leds_set_initialized();
    multicore_fifo_push_blocking(1);

    uint32_t t_uart_rx  = 0;
    uint32_t t_uart_tx  = 0;
    uint32_t t_bat      = 0;
    uint32_t t_led      = 0;

    while (true) {
        uint32_t now = millis();

        tof_update();

        if (now - t_uart_rx >= 10) {
            t_uart_rx = now;
            uart_receive();
        }

        if (now - t_uart_tx >= 100) {
            t_uart_tx = now;
            uart_send_telemetry();
        }

        if (now - t_bat >= 1000) {
            t_bat = now;
            battery_update();

            uint16_t mv = battery_get_mv();
            STATE_LOCK();
            g_state.battery_mv = mv;
            STATE_UNLOCK();

            if (battery_low()) {
                leds_set_mode(LED_LOW_BAT);
            }
        }

        static uint32_t t_tof_share = 0;
        if (now - t_tof_share >= 10) {
            t_tof_share = now;
            STATE_LOCK();
            for (int i = 0; i < TOF_COUNT; i++) {
                g_state.tof_mm[i] = tof_get(i);
            }
            STATE_UNLOCK();
        }

        STATE_LOCK();
        bool    fresh     = g_state.cmd_fresh;
        uint8_t led_mode  = g_state.cmd_led_mode;
        bool    hbr_fault = g_state.hbr_fault;
        STATE_UNLOCK();

        if (hbr_fault) {
            leds_set_mode(LED_FAULT);
        } else if (!battery_low() && fresh) {
            leds_set_mode((LedMode)led_mode);
        }

        if (now - t_led >= 20) {
            t_led = now;
            leds_update();
        }
    }
}


//  SETUP — Core 0

void setup() {
    Serial.begin(115200);
    delay(1500);
    Serial.println("\n=== WRO Robot booting ===");
    

    mutex_init(&g_mutex);
    mutex_init(&g_wire_mutex);

    Wire.setSDA(PIN_I2C_SDA);
    Wire.setSCL(PIN_I2C_SCL);
    Wire.begin();
    Wire.setClock(I2C_CLOCK_HZ);
    Wire.setTimeout(I2C_TIMEOUT_MS);

    motors_init();
    encoder_init();
    pid_init();

    // Initialize the IMU before core 1 starts using Wire.
    imu_init();
    for (int i = 0; i < TOF_COUNT; ++i) g_state.tof_mm[i] = TOF_INVALID_MM;

    multicore_launch_core1(core1_main);
    multicore_fifo_pop_blocking();

    motion_enable(true);

    Serial.println("=== Boot complete ===\n");

    t_pid   = millis();
    t_imu   = millis();
    t_servo = millis();
    t_telem = millis();
}

//  LOOP — Core 0

void loop() {
    uint32_t now = millis();
    if (now - t_telem >= 100) {
        Serial.printf("yaw=%.2f\n", imu_get_yaw());
    }

    // IMU update — 20ms 
    if (now - t_imu >= 20) {
        t_imu = now;
        imu_update();
    }

    // Servo slew — 20ms
    if (now - t_servo >= 20) {
        t_servo = now;
        servo_update();
    }

    // PID + motor update — 10ms
    if (now - t_pid >= 10) {
        float dt = (now - t_pid) / 1000.0f;
        t_pid = now;

        // Always read RPM exactly once - it consumes the delta
        float rpm_magnitude = encoder_get_rpm(dt);

        STATE_LOCK();
        int8_t  dir     = g_state.cmd_dir;
        uint8_t speed   = g_state.cmd_speed;
        uint8_t servo_a = g_state.cmd_servo;
        g_state.cmd_fresh = false;
        STATE_UNLOCK();

        // Always update servo target regardless of motor state
        servo_set(servo_a);

        bool fault = motion_fault();
        STATE_LOCK();
        g_state.hbr_fault = fault;
        STATE_UNLOCK();

        if (fault) {
            motors_stop();
            pid_reset();
        } else if (dir == MOT_STOP) {
            motors_stop();
            pid_reset();
        } else {
            float target_rpm = (speed / 255.0f) * 800.0f;
            if (dir == MOT_BACKWARD) target_rpm = -target_rpm;

            pid_set_target(target_rpm);

            float current_rpm = rpm_magnitude;
            int   pwm         = pid_compute(current_rpm, dt);

            if (pwm == 0) {
                motors_stop();
            } else if (pwm > 0) {
                motors_set(MOT_FORWARD,  (uint8_t) pwm);
            } else {
                motors_set(MOT_BACKWARD, (uint8_t)-pwm);
            }
        }
    }

    // Telemetry to shared state — 100ms 
    if (now - t_telem >= 100) {
        t_telem = now;

        int16_t yaw10 = (int16_t)(imu_get_yaw() * 10.0f);
        int32_t enc   = encoder_get_ticks();

        STATE_LOCK();
        g_state.imu_yaw   = yaw10;
        g_state.enc_ticks = enc;
        STATE_UNLOCK();
    }
}

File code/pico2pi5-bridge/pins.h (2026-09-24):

#pragma once

// ── UART (to/from Pi 5) 
#define PIN_UART_TX       0
#define PIN_UART_RX       1

// Encoder
#define PIN_ENC_A         2
#define PIN_ENC_B         3

// I2C (VL53L1X + MPU6050) 
#define PIN_I2C_SDA       4
#define PIN_I2C_SCL       5

// Shared bus: 400 kHz, bounded transactions (Arduino-Pico Wire).
#define I2C_CLOCK_HZ      400000
#define I2C_TIMEOUT_MS    5

// ToF XSHUT  
#define PIN_XSHUT_1       6 // FRONT
#define PIN_XSHUT_2   7   // LEFT
#define PIN_XSHUT_3   8   // RIGHT
#define PIN_XSHUT_4   9   // REAR (AUX telemetry slot)

// Motors (DRV8833) 
#define PIN_MOT1_A        10
#define PIN_MOT1_B        11
#define PIN_MOT2_A        12
#define PIN_MOT2_B        13

// Motion enable (nSLEEP + servo MOSFET)
#define PIN_MOTION_EN     14

// Servo 
#define PIN_SERVO         15

// WS2812 Indicator LEDs (8x)
#define PIN_LEDS          26
#define NUM_LEDS          8

// DRV8833 nFAULT (input) 
#define PIN_NFAULT        27

// Battery ADC 
#define PIN_BAT1_ADC      29
// PIN_BAT2_ADC (28) — wiring error, unused

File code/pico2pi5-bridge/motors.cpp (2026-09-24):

#include "motors.h"
#include "pins.h"
#include <Arduino.h>
#include <Servo.h>
#include <hardware/pwm.h>
#include <hardware/clocks.h>

static Servo   g_servo;
static uint8_t g_servo_angle  = 90;   // current position
static uint8_t g_servo_target = 90;   // commanded position

// Set a single GPIO to 16kHz PWM via hardware API, bypassing the
// global analogWriteFreq so the Servo library's slice is never touched.
static void set_motor_pin_pwm(uint8_t pin) {
    uint slice = pwm_gpio_to_slice_num(pin);
    uint chan  = pwm_gpio_to_channel(pin);

    gpio_set_function(pin, GPIO_FUNC_PWM);

    // RP2350 default sys clock = 150MHz
    // 150,000,000 / (16000 * 256) ≈ 36.6
    uint32_t sys_hz = clock_get_hz(clk_sys);
    float    clkdiv = (float)sys_hz / (16000.0f * 256.0f);

    pwm_set_clkdiv(slice, clkdiv);
    pwm_set_wrap(slice, 255);
    pwm_set_chan_level(slice, chan, 0);
    pwm_set_enabled(slice, true);
}

static void motor_pwm_write(uint8_t pin, uint8_t value) {
    pwm_set_chan_level(pwm_gpio_to_slice_num(pin),
                       pwm_gpio_to_channel(pin),
                       value);
}

void motors_init() {
    pinMode(PIN_MOTION_EN, OUTPUT);
    pinMode(PIN_NFAULT, INPUT_PULLUP);

    motion_enable(false);

    set_motor_pin_pwm(PIN_MOT1_A);
    set_motor_pin_pwm(PIN_MOT1_B);
    set_motor_pin_pwm(PIN_MOT2_A);
    set_motor_pin_pwm(PIN_MOT2_B);

    motors_stop();

    // MG90S: 500–2400us covers full 180 degrees without binding
    g_servo.attach(PIN_SERVO, 500, 2400);
    g_servo.write(90);

    Serial.println("[OK] Motors + servo init");
}

void motion_enable(bool en) {
    // Controls DRV8833 nSLEEP AND servo power — same pin
    digitalWrite(PIN_MOTION_EN, en ? HIGH : LOW);
}

bool motion_fault() {
    return digitalRead(PIN_NFAULT) == LOW;
}

void motors_stop() {
    motor_pwm_write(PIN_MOT1_A, 0);
    motor_pwm_write(PIN_MOT1_B, 0);
    motor_pwm_write(PIN_MOT2_A, 0);
    motor_pwm_write(PIN_MOT2_B, 0);
    motion_enable(false);   // cuts power to DRV8833 and servo together
}

void motors_set(int8_t direction, uint8_t speed) {
    if (motion_fault()) {
        motors_stop();
        Serial.println("[WARN] DRV8833 fault! Motors stopped.");
        return;
    }

    switch (direction) {
        case MOT_FORWARD:
            motion_enable(true);
            motor_pwm_write(PIN_MOT1_A, speed);
            motor_pwm_write(PIN_MOT1_B, 0);
            motor_pwm_write(PIN_MOT2_A, speed);
            motor_pwm_write(PIN_MOT2_B, 0);
            break;

        case MOT_BACKWARD:
            motion_enable(true);
            motor_pwm_write(PIN_MOT1_A, 0);
            motor_pwm_write(PIN_MOT1_B, speed);
            motor_pwm_write(PIN_MOT2_A, 0);
            motor_pwm_write(PIN_MOT2_B, speed);
            break;

        case MOT_STOP:
        default:
            motors_stop();
            break;
    }
}

void servo_set(uint8_t angle) {
    g_servo_target = constrain(angle, 0, 180);
}

void servo_update() {
    if (g_servo_angle == g_servo_target) return;

    if (g_servo_angle < g_servo_target) {
        g_servo_angle = (uint8_t)min((int)g_servo_angle + SERVO_SLEW_RATE, (int)g_servo_target);
    } else {
        g_servo_angle = (uint8_t)max((int)g_servo_angle - SERVO_SLEW_RATE, (int)g_servo_target);
    }

    g_servo.write(g_servo_angle);
}

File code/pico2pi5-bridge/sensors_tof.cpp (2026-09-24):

#include "sensors_tof.h"
#include "shared_state.h"
#include "pins.h"
#include <Arduino.h>
#include <Wire.h>
#include <VL53L1X.h>

namespace {
constexpr uint8_t kDefaultAddress = 0x29;
constexpr uint32_t kSideBudgetUs = 20000, kSidePeriodMs = 25;
constexpr uint32_t kParkingBudgetUs = 33000, kParkingPeriodMs = 40;
constexpr uint32_t kResetMs = 2;
constexpr uint32_t kBootMs = 10;
constexpr uint32_t kInitTimeoutMs = 100;
constexpr uint32_t kPollSlotMs = 2; // One sensor per slot: 8 ms sweep for four.
constexpr uint32_t kFreshMs = 150;
constexpr uint32_t kFrameTimeoutMs = 250;
constexpr uint32_t kRetryMs = 5000;
static_assert(kSidePeriodMs * 1000 >= kSideBudgetUs + 4000, "Side timing margin");
static_assert(kParkingPeriodMs * 1000 >= kParkingBudgetUs + 4000, "Parking timing margin");
static_assert((TOF_ENABLED_MASK & ~0x0F) == 0, "Only four ToF slots exist");

struct Config {
    uint8_t pin, address;
    uint16_t maxMm;
    uint32_t budgetUs, periodMs;
    const char* name;
};
const Config config[TOF_COUNT] = {
    {PIN_XSHUT_4, 0x30, 150, kParkingBudgetUs, kParkingPeriodMs, "Rear"},
    {PIN_XSHUT_2, 0x31, 600, kSideBudgetUs, kSidePeriodMs, "Left"},
    {PIN_XSHUT_3, 0x32, 600, kSideBudgetUs, kSidePeriodMs, "Right"},
    {PIN_XSHUT_1, 0x33, 150, kParkingBudgetUs, kParkingPeriodMs, "Front"}
};

// Pololu's last_status only describes the LAST write, and does not report
// short requestFrom() reads. Latch every failure across an entire operation.
// This forwarding adapter uses Arduino-Pico's virtual TwoWire methods. It
// never begins/ends a second controller; all traffic uses the existing Wire.
class CheckedWire : public TwoWire {
public:
    CheckedWire() : TwoWire(i2c0, PIN_I2C_SDA, PIN_I2C_SCL) {}
    void clear() { failed = false; }
    bool ok() const { return !failed; }
    void beginTransmission(uint8_t address) override {
        if (!failed) Wire.beginTransmission(address);
    }
    size_t write(uint8_t value) override {
        if (failed) return 0;
        size_t n = Wire.write(value);
        if (n != 1) failed = true;
        return n;
    }
    size_t write(const uint8_t* data, size_t size) override {
        if (failed) return 0;
        size_t n = Wire.write(data, size);
        if (n != size) failed = true;
        return n;
    }
    uint8_t endTransmission(bool stop) override {
        if (failed) return 4;
        uint8_t status = Wire.endTransmission(stop);
        if (status != 0) failed = true;
        return status;
    }
    uint8_t endTransmission() override { return endTransmission(true); }
    size_t requestFrom(uint8_t address, size_t size, bool stop) override {
        if (failed) return 0;
        size_t n = Wire.requestFrom(address, size, stop);
        if (n != size) failed = true;
        return n;
    }
    size_t requestFrom(uint8_t address, size_t size) override {
        return requestFrom(address, size, true);
    }
    int read() override {
        int value = failed ? -1 : Wire.read();
        if (value >= 0) return value;
        failed = true;
        // Library configuration math cannot safely consume 0 or 0xFF for
        // oscillator/VCSEL registers. A failed operation is ALWAYS discarded;
        // this filler only lets the library unwind without divide-by-zero.
        return 1;
    }
    int available() override { return failed ? 0 : Wire.available(); }
private:
    bool failed = false;
};
CheckedWire bus;
VL53L1X sensors[TOF_COUNT];

struct State {
    bool running = false;
    bool sampled = false;
    uint16_t samples[3] = {};
    uint8_t next = 0;
    uint16_t distance = TOF_INVALID_MM;
    uint32_t lastValid = 0, lastFrame = 0, downSince = 0;
    uint32_t retryDelay = kResetMs;
};
State state[TOF_COUNT];
int8_t booting = -1; // Only this sensor may be at 0x29.
uint32_t releasedAt = 0, lastPoll = 0;
uint8_t pollIndex = 0, recoveryIndex = 0;

bool elapsed(uint32_t now, uint32_t then, uint32_t interval) {
    return uint32_t(now - then) >= interval;
}
void holdReset(uint8_t i) {
    digitalWrite(config[i].pin, LOW); // Latch LOW before enabling output.
    pinMode(config[i].pin, OUTPUT);
}
void invalidate(uint8_t i) {
    state[i].sampled = false;
    state[i].distance = TOF_INVALID_MM;
    state[i].next = 0;
}
void resetBank() {
    for (uint8_t i = 0; i < TOF_COUNT; ++i) {
        holdReset(i);
        state[i] = State{};
        state[i].downSince = millis();
    }
    booting = -1;
}
void retire(uint8_t i) {
    holdReset(i); // Never leave a failed/unaddressed device awake.
    state[i].running = false;
    invalidate(i);
    state[i].downSince = millis();
    state[i].retryDelay = kRetryMs;
    if (booting == i) booting = -1;
}

// Caller holds WIRE_LOCK. Probe status is independent of CheckedWire's latch.
bool responds(uint8_t address) {
    Wire.beginTransmission(address);
    return Wire.endTransmission() == 0;
}
bool configure(uint8_t i) {
    // XSHUT restores the hardware address AND requires fresh library state
    // (address, calibration flags, saved VHV settings, oscillator cache).
    sensors[i] = VL53L1X();
    VL53L1X& sensor = sensors[i];
    sensor.setBus(&bus);
    sensor.setTimeout(kInitTimeoutMs);
    bus.clear();
    if (sensor.readReg16Bit(VL53L1X::IDENTIFICATION__MODEL_ID) != 0xEACC || !bus.ok()) return false;
    if ((sensor.readReg(VL53L1X::FIRMWARE__SYSTEM_STATUS) & 1) == 0 || !bus.ok()) return false;
    if (sensor.readReg16Bit(VL53L1X::OSC_MEASURED__FAST_OSC__FREQUENCY) == 0 || !bus.ok()) return false;
    if (sensor.readReg16Bit(VL53L1X::RESULT__OSC_CALIBRATE_VAL) == 0 || !bus.ok()) return false;
    if (!sensor.init() || !bus.ok() || sensor.timeoutOccurred()) return false;
    sensor.setAddress(config[i].address);
    if (!bus.ok()) return false;
    if (sensor.readReg(VL53L1X::I2C_SLAVE__DEVICE_ADDRESS) != config[i].address || !bus.ok()) return false;
    if (sensor.readReg16Bit(VL53L1X::IDENTIFICATION__MODEL_ID) != 0xEACC || !bus.ok()) return false;
    // The released sensor must have left the default address.
    if (responds(kDefaultAddress)) return false;
    if (!sensor.setDistanceMode(VL53L1X::Short) || !bus.ok()) return false;
    if (!sensor.setMeasurementTimingBudget(config[i].budgetUs) || !bus.ok()) return false;
    uint32_t actualBudget = sensor.getMeasurementTimingBudget();
    if (!bus.ok() || actualBudget < config[i].budgetUs - 1000 || actualBudget > config[i].budgetUs + 1000) return false;
    sensor.startContinuous(config[i].periodMs);
    return bus.ok();
}
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

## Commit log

2026-08-31 Add readme for schematic diagrams and Gerber files
2026-08-31 Add finalized robot schematic diagram
2026-08-31 Revise README with team and robot details
    Updated README to provide detailed information about Team Elektron, robot specifications, assembly process, and code explanation.
2026-09-06 Add revised steering mechanism
    Fixed steering alignment and instability from the National championship.
    [newsteering-arm-adapter.stl, newsteering-arm-left.stl, newsteering-arm-right.stl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]
2026-09-10 Upload final PCB design gerber file
2026-09-24 Add revised pico bridge code for new ToF logic
2026-09-24 Update open_challenge.py for version 3 and tuning
    Updated version number and tuning parameters for motor speeds, servo values, and detection settings. Adjusted comments for clarity and consistency.
2026-09-24 Refactor README for improved formatting and clarity
    Updated the README to replace HTML tags with tables for better formatting and clarity. Adjusted gear ratio specifications and improved descriptions of the driving and steering systems.
2026-09-27 Finalized pcb with JLCPCB/EasyEDA sponsor logos.
2026-09-27 Finalized BOM from last order
    [BOM_WRO-FE-2026-EUROPE_2026-09-27.csv]
2026-09-30 Add additional pictures of our new PCB
2026-10-06 Improve clarity of steering system description
    Clarified description of steering power transfer and its benefits.
2026-10-09 Revise open and obstacle challenge descriptions in README
    Updated the open challenge section to describe the robot's functionality using color detection and IMU sensors. Added details about the obstacle challenge and its mapping capabilities.
2026-10-12 Revise open-challenge-cv description in README
    Updated the description of the 'open-challenge-cv' folder to include fallback sensor support.
2026-10-12 Add new chassis design and 3d printable config
    Printable for ORCA slicer
2026-10-12 Add new hotswap battery holders
    Print M3 nuts inside of design (pause at layer 5)
2026-10-12 New modular camera tower design
2026-10-12 add imu pic
2026-10-12 new chassis pic
2026-10-12 new steering pic
2026-10-12 Replace old PCB images with new ones
    Updated images in the README to new PCB photos.
2026-10-12 charge circuit pic
